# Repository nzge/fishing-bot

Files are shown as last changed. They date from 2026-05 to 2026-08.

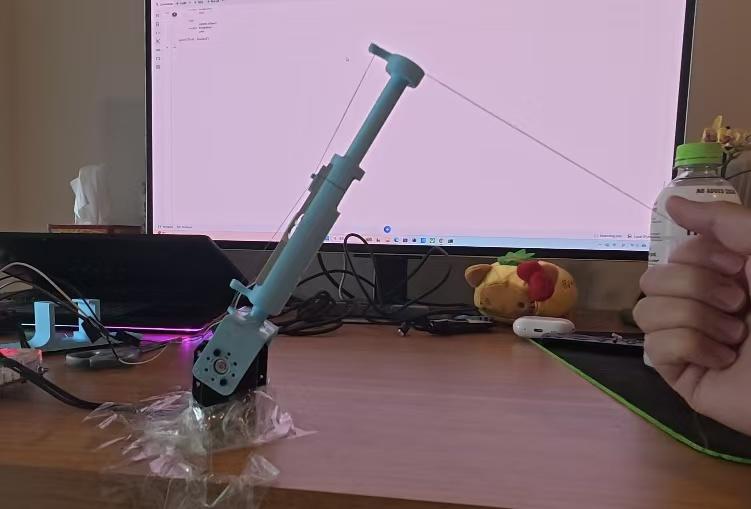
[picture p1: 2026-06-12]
docs/presentation/final presentation/ppt/media/image6.jpg

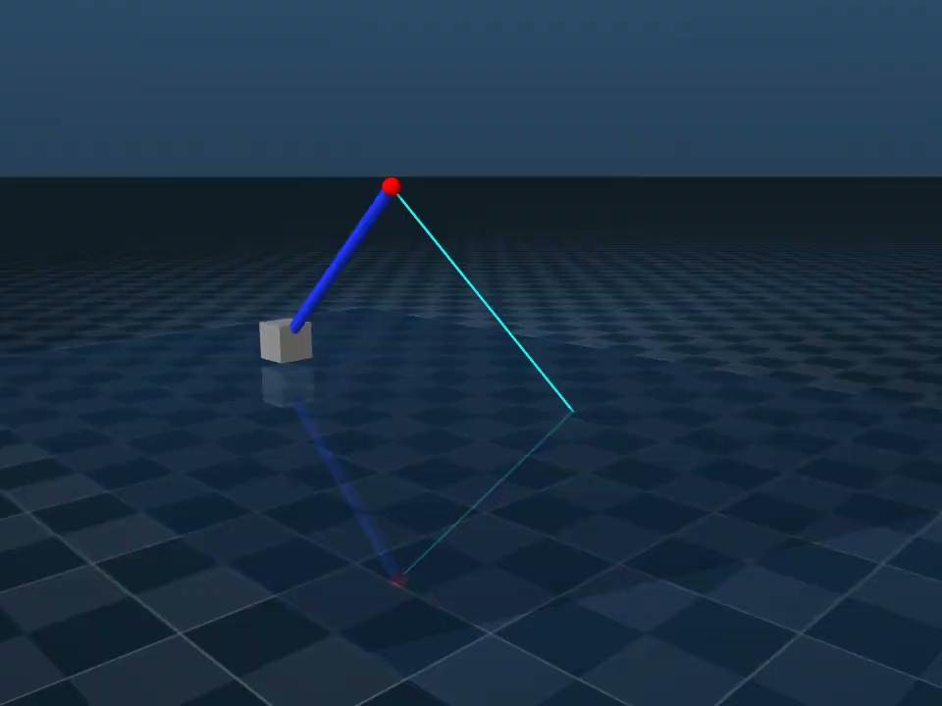
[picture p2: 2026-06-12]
docs/presentation/final presentation/ppt/media/image5.jpg

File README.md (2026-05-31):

# fishing-bot (MAE 263C)
A fishing robot

Codebase documentation: https://nzge.github.io/fishing-bot/

Tweak your fishing-robot.urdf.xacro (in your text editor).
Compile the Xacro: xacro fishing-robot.urdf.xacro use_sim:=true > fishing-robot_sim.urdf
Launch the viewer: python3 -m mujoco.viewer --file fishing-robot_sim.urdf
Inspect your meshes and joints.

## Loading mujoco viewer
- Navigate to the workspace root: cd ~/fishing-bot
- Activate your virtual environment: source .venv/bin/activate
- Launch the viewer with your XML file: python3 -m mujoco.viewer --file sim/fishing_robot.xml

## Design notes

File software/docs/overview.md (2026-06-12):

# Architecture Overview

The stack is built around a **single sim-to-real switch** (`use_sim`). The same
application nodes and topic *names* run in both modes; the hardware plugin,
optional controllers, and tension data source change.

This page is the **navigation hub**. For exhaustive detail, follow the links below.

## Start here

| I want to… | Go to |
| --- | --- |
| Understand each Python package in depth | {doc}`packages/index` |
| See all ROS 2 nodes & topics (sim vs HW) | {doc}`ros2/index` |
| Download diagrams for my report | {doc}`ros2/diagram_exports` |
| Look up launch args / YAML params | {doc}`_generated/reference/index` |
| Read Python class/function docs | {doc}`_generated/reference/api` |
| Build and run the stack | {doc}`getting_started` |

## System context

```{include} _generated/ros_graph/fragments/package_architecture.md
```

## The sim-to-real switch

The `use_sim` launch argument is resolved at **xacro preprocess time**, which
swaps the `<hardware>` plugin in the URDF *before* the controller manager loads
it:

```{list-table}
:header-rows: 1
:widths: 20 40 40

* - Concern
  - `use_sim:=true` (simulation)
  - `use_sim:=false` (hardware)
* - Hardware plugin
  - `mujoco_ros2_control`
  - `dynamixel_hardware`
* - Controller host
  - MuJoCo's bundled `ros2_control_node`
  - Standalone `controller_manager`
* - Extra ros2_control
  - `fish_effort_controller`, `tension_sensor_broadcaster`
  - *(none beyond arm controllers)*
* - Tension source
  - MuJoCo line stretch model (+ FTS fallback)
  - HX711 load cell
* - Disturbance
  - `planning/fish_agent`
  - Real fish / manual load
* - Sim-only URDF
  - `fish_swim` joint, `tension_sensor` FTS
  - Omitted from HW URDF
```

Full branching logic: {doc}`packages/bringup`.

## Closed-loop control

Both modes implement the same ROS-level tension regulation loop:

```{include} _generated/ros_graph/fragments/control_loop.md
```

Controller internals (state machine, admittance vs force-feedback):
{doc}`packages/control`.

## ROS 2 graphs at a glance

### Simulation

```{include} _generated/ros_graph/fragments/simulation_ros2_graph.md
```

Detailed node/topic tables: {doc}`ros2/simulation`.

### Hardware

```{include} _generated/ros_graph/fragments/hardware_ros2_graph.md
```

Detailed node/topic tables: {doc}`ros2/hardware`.

## Packages at a glance

```{list-table}
:header-rows: 1
:widths: 18 18 64

* - Package
  - Build type
  - Role
* - {doc}`packages/bringup`
  - ament_cmake
  - Top-level launch orchestration, controller config.
* - {doc}`packages/control`
  - ament_python
  - Admittance & force-feedback tension controllers.
* - {doc}`packages/sensors`
  - ament_python
  - `FishingTension` publisher (HX711 or sim stretch model).
* - {doc}`packages/planning`
  - ament_python
  - Virtual fish disturbance (**sim only**).
* - {doc}`packages/diagnostics`
  - ament_python
  - Run recorder + hardware bring-up self-test.
* - {doc}`packages/description`
  - ament_cmake
  - URDF/xacro, MuJoCo MJCF, STL meshes.
* - {doc}`packages/interfaces`
  - ament_cmake
  - `FishingTension.msg`.
```

## Layered architecture

```{mermaid}
flowchart TB
    subgraph L0["Layer 0 — Physical"]
        SIM["MuJoCo physics + tendon"]
        HW["Dynamixel + HX711"]
    end
    subgraph L1["Layer 1 — ros2_control"]
        CM["controller_manager / mujoco_ros2_control"]
        CTRL["joint_state_broadcaster · position_trajectory_controller"]
        SIMCTRL["fish_effort · tension_sensor (sim)"]
    end
    subgraph L2["Layer 2 — Application (Python)"]
        APP["control · sensors · planning · diagnostics"]
    end
    subgraph L3["Layer 3 — Orchestration"]
        BR["bringup/robot.launch.py"]
    end
    L0 --> L1
    L1 --> L2
    L3 --> L1
    L3 --> L2
```

## Data-flow summary

| Signal | Sim origin | HW origin | Consumer(s) |
| --- | --- | --- | --- |
| Joint positions | MuJoCo → `joint_state_broadcaster` | Dynamixel encoders | `control`, `diagnostics` |
| Line tension | Stretch model / FTS → `load_cell_node` | HX711 → `load_cell_node` | `control`, `diagnostics` |
| Joint commands | `control` → `position_trajectory_controller` | same | MuJoCo / Dynamixel |
| Fish force | `fish_agent` → `fish_effort_controller` | N/A | MuJoCo only |

Auto-generated topic index: {doc}`_generated/ros_graph/topic_index`.

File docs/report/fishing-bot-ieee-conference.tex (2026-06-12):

\documentclass[conference]{IEEEtran}
\IEEEoverridecommandlockouts

\usepackage[utf8]{inputenc}
\usepackage[T1]{fontenc}
\usepackage{cite}
\usepackage{amsmath,amssymb,amsfonts}
\usepackage{algorithmic}
\usepackage{graphicx}
\usepackage{textcomp}
\usepackage{xcolor}
\usepackage{url}
\usepackage{float}

\begin{document}

\title{Autonomous Robotic Fishing Line Tension Regulation Using Admittance Control}

\author{\IEEEauthorblockN{Nathan Ge}
\IEEEauthorblockA{\textit{Dept. of MAE} \\
\textit{UCLA}\\
Los Angeles, CA, USA}
\and
\IEEEauthorblockN{Chaoyi Hu}
\IEEEauthorblockA{\textit{Dept. of MAE} \\
\textit{UCLA}\\
Los Angeles, CA, USA}
\and
\IEEEauthorblockN{Julie Nguyen}
\IEEEauthorblockA{\textit{Dept. of MAE} \\
\textit{UCLA}\\
Los Angeles, CA, USA}
\and
\IEEEauthorblockN{Xiang Zhou}
\IEEEauthorblockA{\textit{Dept. of MAE} \\
\textit{UCLA}\\
Los Angeles, CA, USA}
}

\maketitle

\begin{abstract}
This project explores the potential of autonomous robotic fishing framework. To carry the problem into an engineering lens to build a technical framework around, we centered our robot’s function on the fishing line tension aspect of the fishing pipeline which is modelled as a force control problem. Tension regulation is fundamentally characterized by the balance of overpulling which risks the line snapping and underpulling which can lose the fish. Good anglers will respond by dynamically adjusting the orientation of the rod with intuition and feel, keeping the line tension in a safe zone. The robot will perform this balancing act intelligently with sensor feedback and precise motor control.
\end{abstract}

\begin{IEEEkeywords}
tension regulation, admittance control, robotic fishing, ROS2, force control
\end{IEEEkeywords}

\section{Overview}
This project explores the potential of autonomous robotic fishing framework. To carry the problem into an engineering lens to build a technical framework around, we centered our robot’s function on the fishing line tension aspect of the fishing pipeline which is modelled as a force control problem. Tension regulation is fundamentally characterized by the balance of overpulling which risks the line snapping and underpulling which can lose the fish. Good anglers will respond by dynamically adjusting the orientation of the rod with intuition and feel, keeping the line tension in a safe zone. The robot will perform this balancing act intelligently with sensor feedback and precise motor control.

Similar robotic fishing systems have been explored in previous projects. AlYaseen et al.\ developed an autonomous fishing rod that can detect fish bites, pull the line, and stop the motor when high resistance is detected to avoid cutting the line~\cite{b1}. This is closely related to our project because both systems use the fishing-line force as an important feedback signal. Another robotic fishing pole project used an Arduino-controlled mechanical system to cast and reel automatically through smartphone or computer control~\cite{b2}. These examples show that fishing is a suitable application for automation and robotic actuation.

Fishing has also been studied as a force-feedback and haptic simulation problem. The Stanford CHARM Lab developed a haptic fishing robot/simulator to create realistic force feedback for the user~\cite{b3}. This supports the motivation of our project because the key part of the fishing experience is not only moving the rod, but also reacting to the changing resistance from the fish. Our project extends this idea by using a physical robotic rod and an admittance controller to convert measured tension into rod motion.

The resultant robot platform is a 1 DOF robotic fishing system to control line tension following the hook set fishing phase. The robot employs sensor-based feedback control to manage tension regulation and disturbance rejection. The tension in the fishing line is detected by a load sensor, and the robot controls the rod pitch angle based on the error of the detected tension. The control system logic was modeled and solidified in simulation as a tethered robot in which the fish-like load is an external disturbance via the line. The project also creates a foundation for future work on more realistic multi-DOF fishing robots or autonomous fishing mechanisms.

\section{Control Objectives}
To carry the problem into an engineering lens to build a technical framework around, fishing can be characterized by three discrete modes: fish discovery (pre hook-set), tension regulation (post hook-set), and reeling.

Fish discovery describes the phase in which the fishing line is ‘cold’ and waiting for a fish to bite. The controller looks for a disturbance signal to indicate fish interest. A jigging action that mimics live bait may be used in this phase to increase fish hooking probability. This phase also includes holes/gaps in tension sensing caused by a fish already hooked on that escapes the jurisdiction of the control domain. Algorithms/action routines may be employed to restore control over the fish.

Looking past fish discovery is the tension regulation stage, the project’s primary control objective, which centers on maintaining tension through the fishing line. The general control structure involves a physical load sensor that approximates the force through the line, and control algorithms that take this information to modulate the tension estimation data. Tension accommodation lends itself naturally to admittance control or some sort of force regulation control methodology, both of which became primary control methods of exploration for this project.
\begin{itemize}
\item Tension regulation
\item Virtual mass-spring-damper (MSD) admittance loops
\item Highly stochastic loads handling
\end{itemize}

An additional reeling component may be added to successfully bring the fish to the desired endpoint. Reeling will also require additional hardware to pull the string inward. This would complicate the load sensing packaging and add mechanical complexity that comes with a reeling system. This particular system was not heavily pursued in our research, leaving it an avenue of future development.

\section{Methods}

\subsection{Hardware}
Image of physical robot:

\begin{figure}[H]
\centerline{}
\caption{Physical robot.}
\label{fig:physical_robot}
\end{figure}

Wiring diagram:

\begin{figure}[H]
\centerline{}
\caption{Wiring diagram.}
\label{fig:wiring_diagram}
\end{figure}

\subsection{Codebase and Simulation}
Additional details can be found in https://nzge.github.io/fishing-bot/

Building out the ROS2 codebase such that the control logic interacts seamlessly with Mujoco simulation and hardware control

\begin{table}[H]
\caption{Table: Package Descriptions}
\begin{center}
\begin{tabular}{|l|p{5.5cm}|}
\hline
\textbf{Package} & \textbf{Description} \\
\hline
Bringup & Launch configuration. Can launch simulation or hardware control based on preference. \\
\hline
Description & Mesh and model descriptors. \\
\hline
Control & Tension control package. \\
\hline
Planning & Used to control randomness of 'fish' behavior. Can be thought of as a fish agent (our disturbance). \\
\hline
Sensors & Sensor readings and publishing. \\
\hline
Interfaces & Develop protocol for inter-node communication. \\
\hline
\end{tabular}
\label{tab:packages}
\end{center}
\end{table}

\subsection{Node Architecture}
The behavior of the fish is simulated as repeatable disturbance for controlled testing.

The controller was tested in a repeatable way with a ROS2 control structure and MuJoCo simulation.

\begin{figure}[H]
\centerline{}
\caption{Node architecture.}
\label{fig:node_architecture}
\end{figure}

\subsection{Mathematical Formulation}
Control Diagram

\begin{figure}[H]
\centerline{}
\caption{Control diagram.}
\label{fig:control_diagram}
\end{figure}

High level Admittance control

The system utilizes a virtual mass-spring-damper system to

\begin{figure}[H]
\centerline{}
\caption{High-level admittance control.}
\label{fig:admittance_control}
\end{figure}

Low level PI control on theta position commands

\begin{figure}[H]
\centerline{}
\caption{Low-level PI control on theta position commands.}
\label{fig:pi_control}
\end{figure}

Inverse and forward Kinematics

\begin{figure}[H]
\centerline{}
\caption{Inverse and forward kinematics.}
\label{fig:kinematics}
\end{figure}

\section{Results}

\subsection{Error Assessment}

\subsubsection{1. Engagement and safety logic}
\begin{figure}[H]
\centerline{}
\caption{Figure 1.1. Engagement and recovery supervisor state during the hardware trial.}
\label{fig:engagement_supervisor}
\end{figure}

The engagement supervisor was also evaluated during the hardware trial. Before the line tension reached the bite-trigger condition, the controller remained in the IDLE state and commanded zero PWM, preventing the motor from responding to sensor noise or small disturbances. In this implementation, the controller was activated only when the measured tension exceeded 0.8 N for 0.10 s, representing the initial pulling event after a fish is hooked. During active control, a low-tension condition was detected when the measured tension stayed below 1.0 N. If this condition lasted for more than 1.8 s, the supervisor entered the RECOVERY state to avoid continuously pulling against a slack line. Once the measured tension recovered above 2.0 N, the controller returned to active control. The supervisor state plot shows this sequence, with transitions from IDLE to CONTROL, then to RECOVERY, and finally back to CONTROL after the tension recovered.

\subsubsection{2. Dynamic Controller Response}
\begin{figure}[H]
\centerline{}
\caption{Figure 2.1. Measured tension response during dynamic regulation.}
\label{fig:tension_dynamic}
\end{figure}

The dynamic controller response was evaluated using a trial with larger variations in the applied line tension. Fig. 2.1 shows the measured tension signal used as feedback by the controller. Since the line was pulled manually, the sharp peaks in the tension curve should not be interpreted as a standardized disturbance input. The tension signal also depends on factors such as pulling speed, pulling direction, line slack, and the contact condition of the load cell. Therefore, this figure is mainly used to show the feedback signal received by the controller during a more dynamic pulling condition, rather than to evaluate the tension curve alone.

\begin{figure}[H]
\centerline{}
\caption{Figure 2.2. Controller region switching during dynamic regulation.}
\label{fig:region_switching}
\end{figure}

The controller response to these tension changes is shown more clearly in Fig. 2.2. During the trial, the controller compares the measured tension with the target tension and the deadband, then selects the corresponding control region. When the tension rises above the desired range, the controller switches to the HIGH region, which corresponds to a release action to reduce excessive line tension. When the tension drops below the desired range, the controller returns to the LOW region, where the motor pulls back to recover line tension. The repeated LOW/HIGH transitions show that the controller is actively responding to the sign of the tension error rather than applying a fixed motor command.

\begin{figure}[H]
\centerline{}
\caption{Figure 2.3. PWM command and control components during dynamic regulation.}
\label{fig:pwm_command}
\end{figure}

Fig. 2.3 shows how these feedback decisions are converted into actuator commands. The blue curve is the final PWM command sent to the Dynamixel motor, while the orange and green curves show two major contributing terms: the high-tension release feedforward and the position compensation term. The zero-PWM line separates the two actuation directions. In this implementation, positive PWM commands are associated with release actions during high-tension events, while negative PWM commands are associated with pull-back corrections when the tension becomes too low.

The positive PWM pulses in Fig. 2.3 appears when the controller enters the HIGH region, showing that the controller is actively trying to release the rod and reduce excessive tension. After the tension decreases, the final PWM command becomes negative, which corresponds to the LOW-region pull-back action. The position compensation term changes more slowly because it depends mainly on the rod position rather than the instantaneous tension peak. As a result, the final PWM command is the combined output of tension-based correction and position-based compensation.

Overall, the agreement between Fig. 2.1, Fig. 2.2, and Fig. 2.3 shows the intended closed-loop behavior of the controller. Fig. 2.1 provides the measured tension feedback, Fig. 2.2 shows the corresponding HIGH/LOW region selection based on the tension error, and Fig. 2.3 shows the motor command generated from this feedback logic. Together, these results indicate that the robot actively responds to changes in line tension by switching control modes and commanding the actuator in the expected direction.

\subsubsection{3. Post-Transient Regulation Performance}
The post-transient regulation performance was evaluated using a separate hardware trial. This trial should not be interpreted as a standard step-response test, since the external line tension was generated manually rather than by a fixed and repeatable disturbance source. In this hardware setup, the measured tension depends not only on the rod angle, but also on the pulling force applied by hand, line slack, load-cell contact, and motor friction. Therefore, the response is expected to be slower and less uniform than a pure position-control response. For this reason, the later portion of the trial was used to evaluate whether the controller could maintain the line tension near the target once the large engagement and correction motions had passed.

\begin{figure}[H]
\centerline{}
\caption{Figure 3.1. Measured tension response after the initial engagement transient.}
\label{fig:tension_post_transient}
\end{figure}

Fig. 3.1 shows the measured tension response during this trial. The target tension was set to 3.5 N. During the initial engagement phase, the measured tension contains a large transient peak, which is mainly caused by the initial line engagement and manual pulling input. After this transient and the following correction motions, the controller brings the measured tension back toward the target range. In the later part of the trial, the tension remains close to the desired value, showing that the controller can maintain the line tension near the target under a relatively stable pulling condition.

\begin{figure}[H]
\centerline{}
\caption{Figure 3.2. Tension regulation error after the initial transient.}
\label{fig:tension_error}
\end{figure}

The tension regulation error is shown in Fig. 3.2. Instead of treating the full response as a standard settling-time test, the final portion of the trial was used as a post-transient evaluation window. Over this window, the measured tension had an average value of 3.52 N compared with the 3.5 N target. The mean absolute tension error was 0.025 N, and the RMSE was 0.036 N, corresponding to approximately 0.72\% and 1.03\% of the target tension, respectively. These values show that once the large transient response had passed, the controller was able to regulate the line tension with a small remaining error.

\begin{figure}[H]
\centerline{}
\caption{Figure 3.3. Rod joint angle during post-transient tension regulation.}
\label{fig:joint_angle}
\end{figure}

Fig. 3.3 shows the rod joint angle during the same trial, reported in degrees. The joint angle provides additional context for the tension regulation behavior shown in Fig. 3.1 and Fig. 3.2. During the initial engagement and correction phase, the tension error is relatively large, and the actuator changes the rod angle to establish line tension and reduce the error. As the measured tension approaches the target in the later part of the trial, the tension error becomes smaller and the rod joint angle also remains near a stable operating posture. This trend indicates that the actuator adjustment is consistent with the reduction of the tension error. However, the joint angle is not expected to match the tension error exactly, since the measured tension also depends on the manual pulling input, line slack, load-cell contact, and friction. Therefore, Fig. 3.3 is used to show the actuator motion and final rod posture, while Fig. 3.2 remains the main performance metric for tension regulation.

\section{Current Challenges}
Although the hardware test shows that the controller can regulate the line tension, the current setup still has several practical limitations. One major limitation is that the external line tension was applied by hand during the experiment rather than generated by a standardized disturbance source. This made the test closer to an actual fishing interaction, but it also means that the measured tension curve is affected by the pulling speed, pulling direction, and line slack. As a result, some sharp peaks and sudden drops in the tension signal should be interpreted as part of the manual interaction with the line, instead of being attributed to the controller alone. Therefore, the hardware results are mainly used to demonstrate the controller behavior under realistic manual interaction rather than to provide a standardized disturbance-response benchmark.

Another important limitation comes from the indirect relationship between motor motion and measured line tension. Unlike a pure position-control task, where the motor angle can be measured and controlled directly, the line tension depends on several physical factors between the actuator and the sensor. For example, line slack, fishing-line compliance, load-cell contact condition, and friction in the mechanism can all affect the measured tension even when the motor command is the same. As a result, small motor motions do not always produce an immediate or proportional change in tension.

This limitation is also related to the PWM-based actuation used in the current implementation. Since the motor is commanded through PWM rather than a precise torque or position controller, small corrective commands may need to overcome static friction, gravity, and mechanical resistance before visible rod motion occurs. This can make the actuator response less smooth during fine tension corrections. Therefore, the tension regulation result should be understood as the combined behavior of the controller, motor actuation, fishing line, and load-cell measurement, rather than as a direct one-to-one mapping between joint angle and tension.

\section{Future Work}
Upon further understanding of the problem, it became clear that this apparently simple tension management task has incredibly deep and rich control ideas embedded beneath the surface. This led to a deep dive of potential control tools that may bolster the robustness of the control system.

\subsection{Algorithms}
First let's consider extensive ideas on the algorithmic front. For one, if we consider taking the 1DOF control problem to the more realistic 2DOF planarized case, nonlinear coupling dynamics and orthogonal subspaces appear. But less obvious is added complication regarding sensing capabilities. Considering our limited 1D load sensing framework, we will require sensor fusion/interpretation techniques to ensure optimal tension estimation in the higher dimensional space (2D). In other words, instead of a direct linear force/tension estimation relation for the 1DOF case, we need to be aware of a more precise tension vector to perform control feedback on. If we use load sensor info and kinematic state via encoders we may employ kinematic variation/dithering to back out the tension vector estimation. But if we decide to use joint torques as well, a sensor fusion technique such as an extended kalman filter may be necessary. Furthermore, the concept of hybrid control may come into play to allow admittance in the tension management force adaptive axis and rigid positional control in perpendicular axes.

Another crucial facet of the control problem is state switching capability. Discrete states are naturally embedded within the fishing control problem, and makes the problem incredibly control rich. The transition from fish searching to hook set, or switching from having fish to losing tension are both examples of discrete switching behavior. The problem can be summarized as this: how do we ensure stable and robust discrete state switching capability? A robust Finite State Machine (FSM) must be prescribed. The current FSM implementation uses basic force thresholding that induces highly volatile “chatter” behavior, or rapid, unstable, and unnecessary state switching behavior. A few stability insurance techniques come to mind to augment our FSM. We can first employ common FSM techniques, two of which being hysteresis and debouncing. Hysteresis may help better characterize switching conditions by enforcing anisotropic force thresholds for entering and exiting a state. Debouncing adds time-based thresholding/conditioning to limit false/rapid triggering.

Another region of focus in the FSM is the transition points themself. We could apply smoothing filters to help initiate bumpless transfer and eliminate unwanted transient spikes in control effort. A crucial function of the controller is to also place the system under regions of controllability. In this particular problem, we want to avoid fish line snapping or losing tension control on the fishing being hooked onto the line. We can use tension break detection (rate of force change) and accompanying funnel synthesis to bound the tracking error control behavior. The idea of funnel synthesis can be applied to the immediate high error case where tension is suddenly lost. Funnel synthesis drops the robot controller into a safe, heavily damped recovery ‘funnel’ in case of line break preventing the robotic arm from violently whipping backward and breaking motors

This funnel synthesis concept can also be applied for control regain.

Additionally, the state behaviors themselves have to be tended to. If admittance control is being used we can use gain scheduling to customize dynamic behaviors specific to a state's concerns.

AI has relevance to control enhancement here as well. We can augment the control loop with an adaptive neural network feedforward term that learns the stochastic frequency of the fish's pulling behavior, effectively predicting the required q\_d before the tension error grows too large. Our preexisting sim-real frameworks can also be set up to build a Sim-to-real training pipeline. We use our simulation framework as an AI training tool to optimize fish tensioning behavior in the real robot. This can be primarily achieved in two ways: either we use direct RL methods to build a neural-based controller, or employ layered RL to tune controller parameters of a pre-designed control framework. Our simulation pipeline can also simply be used for adaptive control tuning without AI.

\subsection{Noise reduction and filtering techniques}
To properly target fishes for catching in an unpredictable open ocean scenario, we may require probabilistic state estimation (HMM, Bayesian filtering). This concept is often important in partial observability/limited info scenarios such as real world RL training cases. Frequency and derivative of the force may be used to distinguish between fake disturbances (boat rocking, snag on seaweed) or an actual fish. However, in the case the environment we are operating in (in our scenario it would be the ocean or a body of water) has no partial observability or obstruction concerns, we may simply bypass the problem state estimation seeks to solve by using computer vision to distinguish between a fish and ignorable entities.

\subsection{Hardware}
A few hardware-specific augmentations could be worth studying in the future, to observe their impact on tension management characteristics (transient behaviors, error attenuation, control effort).

The introduction of a redundantly actuated serial joint is one such augmentation with significant control implications. The idea was initially inspired by a desire to emulate rod compliance with active control capability. Then, the larger control picture became clear. The most practical use of the redundant serial joint is the implementation of a macro-micro manipulator structure. The lower heavy base joint handles low-frequency, high-amplitude positioning (like tracking boat's movement). A smaller, redundantly actuated serial joint near the tip can be tuned with a much higher control loop frequency to handle high-frequency stochastic disturbances. As a result, we receive the benefit of inertial decoupling: we get improved torque efficiency as jerky movements are handled by the actuator near the tip and doesn’t cause the heavy base motor downstream to respond unnecessarily and move high inertial loads.

The added joint also opens the possibility of null space optimization with the introduction of infinite joint configurations. This allows us to initiate secondary optimization objectives besides tension management such as torque minimization.

The secondary joint can also be treated as a dynamic impedance shaping element, with the redundant motor acting as a dynamically tunable physical stiffness unit that adheres to control needs.

Passive structures are another potential angle for improving dynamic performance. A compliant segment added to the end of the rod can mechanical LPF, dealing with incredibly jerky fish motion in true fishing scenarios as well as improve bumpless transfer stabilization during state transitions to reduce risky torque spikes.

The last hardware-based project enhancement has less to do with the robotic arm itself, but more so about creating an improved real-world testing rig. The idea is to create an actuatable object to mimic a fish that has planarized movement capabilities to perform varied experiments on our hardware system and its accompanying controller design

\subsection{Practical additions}
Other considerations that would bring the automated fishing system closer to a ‘market-available’ product include an actuated hooking system and a tensioning reel mechanism. This would come with its own host of hardware implementation and control framework problems.

\section*{References}

\begin{thebibliography}{00}
\bibitem{b1} M. AlYaseen, O. Alajmi, N. Al-Attal, and A. Al-Saleh, “Autonomous Fishing Rod,” College of Engineering and Applied Sciences, American University of Kuwait, Kuwait, 2019.
\bibitem{b2} J. Cook, “Robotic Fishing Pole Casts and Reels Automatically,” Hackster.io, 2019. [Online]. Available: Hackster.io.
\bibitem{b3} Stanford CHARM Lab, “Haptic Fishing Robot,” Stanford University, 2024. [Online]. Available: Stanford CHARM Lab.
\bibitem{b4} Lai, G., Zhou, S., Yang, W., Wang, X., \& Wang, F. (2023). Prescribed fixed-time adaptive neural control for manipulators with uncertain dynamics and actuator failures. Mathematics, 11(13), 2925. https://doi.org/10.3390/math11132925 Cited by: 4
\end{thebibliography}

\end{document}

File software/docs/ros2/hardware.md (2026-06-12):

# Hardware ROS 2 Graph

Launch command:

```bash
ros2 launch bringup robot.launch.py use_sim:=false
# optional: controller_type:=force_feedback hardware_check:=true
```

## Complete ROS 2 graph

```{include} ../_generated/ros_graph/fragments/hardware_ros2_graph.md
```

**Standalone source:** [`diagrams/hardware_ros2_graph.mmd`](../_static/diagrams/hardware_ros2_graph.mmd)

## What is absent on hardware

These sim-only components are **not spawned** and have **no URDF entries**
when `use_sim:=false`:

| Component | Why absent |
| --- | --- |
| `mujoco_ros2_control` node | Replaced by `controller_manager` |
| `fish_swim` joint | No virtual fish in URDF |
| `fish_effort_controller` | No fish joint to command |
| `tension_sensor_broadcaster` | No MuJoCo FTS sensor |
| `fish_agent` | Launch gated on `use_sim` |
| `/tension_sensor_broadcaster/wrench` | Topic never created |
| `/fish_effort_controller/commands` | Topic never created |
| `fish_link` TF frame | Not in HW URDF |

The dashed **"NOT present"** region in the diagram above summarises this.

## Node reference

### Infrastructure

| Node | Package | Role |
| --- | --- | --- |
| `robot_state_publisher` | `robot_state_publisher` | TF + robot description |
| `controller_manager` (`ros2_control_node`) | `controller_manager` | Realtime loop + `dynamixel_hardware` plugin |

### ros2_control controllers

| Controller | Joints | Notes |
| --- | --- | --- |
| `joint_state_broadcaster` | `Joint_1`, `Joint_2` | Publishes `/joint_states` |
| `position_trajectory_controller` | `Joint_1`, `Joint_2` | Position commands only |

No effort controllers, no sensor broadcasters.

### Application nodes

| Node | Package | Notes |
| --- | --- | --- |
| `admittance_controller` or `force_feedback_controller` | `control` | Same as sim |
| `load_cell_node` | `sensors` | `source:=hardware` — HX711 path |
| `hardware_check` | `diagnostics` | Only when `hardware_check:=true` |

## Topic catalog (hardware)

```{list-table}
:header-rows: 1
:widths: 28 22 18 32

* - Topic
  - Message
  - Publisher → Subscriber
  - Notes
* - `/joint_states`
  - `sensor_msgs/JointState`
  - `joint_state_broadcaster` → `control`, `hardware_check`
  - Dynamixel feedback
* - `/position_trajectory_controller/joint_trajectory`
  - `trajectory_msgs/JointTrajectory`
  - `control` → `position_trajectory_controller`
  - Same interface as sim
* - `/fishing_arm/tension`
  - `interfaces/FishingTension`
  - `load_cell_node` → `control`, `hardware_check`
  - From HX711 (not FTS)
* - `/tf`, `/tf_static`
  - `tf2_msgs/TFMessage`
  - `robot_state_publisher`
  - No `fish_link`
* - `/robot_description`
  - `std_msgs/String`
  - `robot_state_publisher`
  - HW URDF (no fish)
```

### Topics that exist in sim but NOT on hardware

| Topic | Sim publisher |
| --- | --- |
| `/fish_effort_controller/commands` | `fish_agent` |
| `/tension_sensor_broadcaster/wrench` | `tension_sensor_broadcaster` |
| `/clock` (sim time) | MuJoCo sim |

## Physical layer (below ROS)

```{include} ../_generated/ros_graph/fragments/hardware_data_flow.md
```

### Dynamixel path

```
JointTrajectory → position_trajectory_controller → ros2_control → DynamixelHardware
  → USB /dev/ttyUSB0 → XL430 servos (ID 1, 2) → joint encoders → /joint_states
```

### Load cell path

```
Line tension → HX711 ADC → load_cell_node.read_raw_adc()
  → calibration → moving average → /fishing_arm/tension
```

```{warning}
Implement real HX711 I/O in `read_raw_adc()` before deployment. The current
stub generates a synthetic sine wave for development.
```

## Controller differences on hardware

| Concern | Simulation | Hardware |
| --- | --- | --- |
| Jacobian for admittance | Can use TF tip/fish geometry | Falls back to `rod_length * |cos θ|` |
| Disturbance | Deterministic sine from `fish_agent` | Unpredictable real load |
| Latency | Sim-step bound | USB serial + servo response |
| Safety | Physics clamp in MJCF | `safety_tension_limit` E-stop in controller |

## Pre-flight checklist

```bash
# 1. Validate pipeline in sim first
ros2 launch bringup robot.launch.py hardware_check:=true

# 2. Run same check on hardware (controller disabled)
ros2 launch bringup robot.launch.py use_sim:=false hardware_check:=true

# 3. Closed-loop on hardware
ros2 launch bringup robot.launch.py use_sim:=false
```

## Related

- Simulation counterpart: {doc}`simulation`
- Sensor calibration: {doc}`../packages/sensors`
- Export diagram: {doc}`diagram_exports`

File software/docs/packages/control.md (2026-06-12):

# `control` — Tension Controllers

The `control` package implements **closed-loop line-tension regulation** for the
2-DOF fishing arm. It maps measured tension (from {doc}`sensors`) to joint
trajectory commands consumed by `position_trajectory_controller`.

**Source:** `software/src/control/control/`  
**Python API:** {doc}`../_generated/autoapi/control/index`  
**Parameters:** `bringup/config/params.yaml` (keyed by node name)

## Architecture

The package separates **pure control math** from **ROS 2 I/O**:

```{mermaid}
flowchart LR
    subgraph core["fishing_control_core.py (pure Python)"]
        ADM["AdmittanceControllerCore"]
        FFB["ForceFeedbackControllerCore"]
        SM["get_fishing_state()"]
    end
    subgraph ros["fishing_controller_node.py"]
        BASE["FishingControllerBase"]
        ADN["AdmittanceControllerNode"]
        FFN["ForceFeedbackControllerNode"]
    end
    subgraph entry["entry points"]
        E1["admittance_controller.py"]
        E2["force_feedback_controller.py"]
    end
    E1 --> ADN
    E2 --> FFN
    ADN --> BASE
    FFN --> BASE
    ADN --> ADM
    FFN --> FFB
    ADM --> SM
    FFB --> SM
```

| Module | Responsibility |
| --- | --- |
| `fishing_control_core.py` | State machine, tension filtering, admittance & force-feedback algorithms (notebook ports) |
| `fishing_controller_node.py` | ROS subscriptions, safety checks, trajectory publishing, config loading |
| `admittance_controller.py` | Thin `main()` → `AdmittanceControllerNode` |
| `force_feedback_controller.py` | Thin `main()` → `ForceFeedbackControllerNode` |
| `position_test_publisher.py` | Standalone open-loop sinusoid for motor validation (not launched by bringup) |

## Executables

| Command | Node name | Description |
| --- | --- | --- |
| `ros2 run control admittance_node` | `admittance_controller` | Julie's virtual admittance controller |
| `ros2 run control force_feedback_node` | `force_feedback_controller` | Chaoyi's asymmetric P controller |
| `ros2 run control position_test_publisher` | `position_test_publisher` | Manual motor sweep test |

Select at launch: `controller_type:=admittance|force_feedback|none`.

## ROS 2 interfaces

### Subscriptions

| Topic | Type | Callback | Purpose |
| --- | --- | --- | --- |
| `/fishing_arm/tension` | `interfaces/FishingTension` | `_tension_cb` | Measured line tension (N) |
| `/joint_states` | `sensor_msgs/JointState` | `_joint_state_cb` | Current `Joint_1`/`Joint_2` pos & vel |

### Publications

| Topic | Type | Content |
| --- | --- | --- |
| `/position_trajectory_controller/joint_trajectory` | `trajectory_msgs/JointTrajectory` | Position setpoints for active joints |

In **1-DOF mode** (`control_dof:=1`, default), each trajectory point sets
`Joint_1 = joint_1_hold` (locked base yaw) and `Joint_2 = pitch_cmd`.

## Control loop timing

`FishingControllerBase` runs a timer at `control_rate_hz` (default **50 Hz**):

1. **Safety gate** — if no tension received yet, or `|tension| > safety_tension_limit`, hold position (E-stop).
2. **State machine** — `get_fishing_state(t)` → `MONITOR`, `HOOK_SET`, or `REGULATE`.
3. **Tension filter** — exponential smoothing (`tension_filter_alpha`).
4. **Controller update** — algorithm-specific; produces pitch command.
5. **Publish** — `JointTrajectory` with 100 ms horizon.

See the state machine diagram in {doc}`index`.

## State machine

| State | Time window | Behaviour |
| --- | --- | --- |
| `MONITOR` | `t < bite_time` (2.4 s) | Hold `q_init`; admittance uses `f_desired = 0` |
| `HOOK_SET` | `bite_time ≤ t < bite_time + hook_duration` | Smoothstep from `q_init` → `q_hook` |
| `REGULATE` | thereafter | Track `target_tension` (3.5 N default) |

Parameters `bite_time`, `hook_duration`, and angle setpoints (`q_init`, `q_hook`,
`q_neutral`, `q_min`, `q_max`) are shared between both controllers.

## Admittance controller (Julie)

**Class:** `AdmittanceControllerCore` in `fishing_control_core.py`  
**Origin:** `scripts/mojocowithJulieController.ipynb`

Virtual **mass–spring–damper** outer loop with a force–Jacobian mapping:

1. Compute force error `f_desired - f_measured`.
2. Estimate scalar Jacobian `∂(line length)/∂θ` (geometry from TF when available, else `rod_length * |cos θ|` fallback for hardware).
3. Virtual dynamics: `m_v θ̈ = τ_force + τ_spring - b_v θ̇`.
4. Integrate to `theta_cmd`, clip to joint limits.
5. Inner PD loop computes diagnostic torque (not sent directly — `position_trajectory_controller` tracks position).

Key parameters: `m_v`, `b_v`, `k_v`, `k_f`, `kp_track`, `kd_track`, `rod_length`, `j_alpha`.

## Force-feedback controller (Chaoyi)

**Class:** `ForceFeedbackControllerCore`  
**Origin:** `scripts/mojocowithchaoyi'scontroller.ipynb`

Asymmetric proportional mapping from tension error to equilibrium pitch:

- **Below target** (`tension_error < 0`): raise rod with gain `raise_gain`.
- **Above target**: lower rod with gain `lower_gain`.
- Output smoothed via `qeq_alpha` with per-step limit `max_qeq_step`.

Key parameters: `tension_to_angle_gain`, `qeq_alpha`, `max_qeq_step`, `raise_gain`, `lower_gain`.

## Configuration loading

Parameters are declared in `load_admittance_config()` / `load_force_feedback_config()`
by iterating dataclass fields. The node name in launch (`admittance_controller` or
`force_feedback_controller`) must match the key in `params.yaml`:

```yaml
admittance_controller:
  ros__parameters:
    target_tension: 3.5
    ...
force_feedback_controller:
  ros__parameters:
    target_tension: 3.5
    ...
```

## Interactions

```{list-table}
:header-rows: 1
:widths: 22 78

* - Upstream
  - Provides measured tension and joint feedback
* - `sensors` / `load_cell_node`
  - Publishes `/fishing_arm/tension` (`FishingTension`)
* - `joint_state_broadcaster`
  - Publishes `/joint_states`
* - Downstream
  - Executes motion commands
* - `position_trajectory_controller`
  - Subscribes to `/position_trajectory_controller/joint_trajectory`
* - `bringup`
  - Selects which controller executable to launch; suppresses control during `hardware_check`
* - `diagnostics`
  - `recorder` logs tension and joint states; `hardware_check` uses same trajectory topic for open-loop moves
* - `interfaces`
  - Imports `FishingTension` message type
```

## Future: 2-DOF control

`control_dof:=2` is declared but **not yet implemented** — the node logs a warning
and continues in 1-DOF pitch-only mode. The trajectory publisher already has a
stub code path for 2-DOF joint lists.

## Related

- Tuning script: `scripts/tune_tension_control.py` (repo root)
- Compare algorithms: launch with `controller_type:=admittance` vs `force_feedback`
- API reference: {doc}`../_generated/autoapi/control/fishing_control_core/index`

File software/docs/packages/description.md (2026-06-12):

# `description` — Robot Model Assets

The `description` package holds all ** kinematic and simulation assets** for the
fishing arm: URDF/xacro, MuJoCo MJCF, and STL meshes.

**Source:** `software/src/description/`  
**Auto-generated tables:** {doc}`../_generated/reference/packages/description`

There is no runtime Python node — this package is consumed at launch time when
xacro generates the URDF and when MuJoCo loads the MJCF scene.

## Asset inventory

| Asset | Path | Used by |
| --- | --- | --- |
| Xacro macro | `urdf/fishing-robot.urdf.xacro` | `bringup` → `robot_state_publisher`, ros2_control |
| Sim URDF | `urdf/fishing-robot_sim.urdf` | Preprocessed reference |
| HW URDF | `urdf/fishing-robot_hw.urdf` | Preprocessed reference |
| MJCF scene | `urdf/fishing-robot_sim.xml` | `mujoco_ros2_control` plugin |
| Meshes | `meshes/*.STL` | Visual/collision geometry |

## Kinematic tree (both modes)

```{mermaid}
flowchart TB
    BL["base_link"]
    L1["Link_1"]
    L2["Link_2"]
    RT["rod_tip_link"]
    BL -->|"Joint_1 revolute (yaw)"| L1
    L1 -->|"Joint_2 revolute (pitch)"| L2
    L2 -->|"rod_tip_joint fixed"| RT
```

| Joint | Type | Axis | ros2_control interfaces |
| --- | --- | --- | --- |
| `Joint_1` | revolute | Z | position cmd; pos/vel/effort state |
| `Joint_2` | revolute | Y | position cmd; pos/vel/effort state |
| `rod_tip_joint` | fixed | — | Defines load cell frame |

Simulation adds:

| Joint | Type | Purpose |
| --- | --- | --- |
| `fish_swim` | prismatic | Virtual fish slide DOF |
| `fish_link` | — | Fish body frame |

## The `use_sim` xacro switch

`fishing-robot.urdf.xacro` accepts:

| Argument | Default | Effect |
| --- | --- | --- |
| `use_sim` | `true` | Select hardware plugin and sim-only joints/sensors |
| `headless` | `false` | MuJoCo viewer visibility (sim only) |

### Simulation block (`use_sim:=true`)

```xml
<plugin>mujoco_ros2_control/MujocoSystemInterface</plugin>
<param name="mujoco_model">.../fishing-robot_sim.xml</param>
<param name="initial_keyframe">starting_pose</param>
<param name="headless">...</param>
```

Additional ros2_control entries:

- **`fish_swim`** joint with effort command interface
- **`tension_sensor`** FTS sensor mapped from MJCF `tension_sensor` sensor

### Hardware block (`use_sim:=false`)

```xml
<plugin>dynamixel_hardware/DynamixelHardware</plugin>
<param name="usb_port">/dev/ttyUSB0</param>
<param name="baud_rate">57600</param>
```

No fish joint, no FTS sensor — only `Joint_1` and `Joint_2`.

## MJCF simulation scene

`fishing-robot_sim.xml` defines:

- Arm bodies matching URDF kinematics
- **Line tendon** between rod tip and fish (stiffness, rest length, damping —
  must match {doc}`sensors` `sim_line_*` parameters)
- **`tension_sensor`** force/torque sensor at rod tip
- **`fish_force`** motor on `fish_swim`
- **`starting_pose`** keyframe applied on boot

The MuJoCo plugin reads the MJCF path from the URDF `<param>` tag — no separate
launch argument needed.

## ros2_control joint ↔ Dynamixel mapping

| Joint | Dynamixel ID | Limits |
| --- | --- | --- |
| `Joint_1` | 1 | ±π rad |
| `Joint_2` | 2 | ±π rad |

Effort limit: 2.5 N·m; velocity limit: 5.76 rad/s (from URDF).

## Interactions

| Package | How it uses `description` |
| --- | --- |
| {doc}`bringup` | Processes xacro with `use_sim`, `headless`; passes URDF to all nodes |
| `mujoco_ros2_control` | Loads MJCF, steps physics, exposes sim joints/sensors |
| `dynamixel_hardware` | Maps URDF joints to USB servos |
| {doc}`sensors` | TF frame names; tendon parameter consistency |
| {doc}`planning` | Fish joint exists in sim URDF/MJCF |
| {doc}`diagnostics` | MJCF path for animation renderer |

## Related

- Full URDF source: [`fishing-robot.urdf.xacro`](https://github.com/nzge/fishing-bot/blob/main/software/src/description/urdf/fishing-robot.urdf.xacro)
- Sim vs HW ROS graphs: {doc}`../ros2/simulation`, {doc}`../ros2/hardware`

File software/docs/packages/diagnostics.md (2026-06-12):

# `diagnostics` — Recording & Bring-Up Tests

The `diagnostics` package provides **observability** (run recording, plots,
animation) and **validation** (open-loop hardware check) for the fishing stack.

**Source:** `software/src/diagnostics/diagnostics/`  
**Python API:** {doc}`../_generated/autoapi/diagnostics/index`  
**Config:** `config/diagnostics_params.yaml`

## Components overview

```{mermaid}
flowchart LR
    subgraph diag["diagnostics package"]
        REC["recorder"]
        HWC["hardware_check"]
        REN["render_animation.py<br/>(subprocess, not a node)"]
    end
    REC -->|"on shutdown"| REN
    BR["bringup"] -->|"record:=true"| REC
    BR -->|"hardware_check:=true"| HWC
```

| Executable | Node name | Launched when | Mode |
| --- | --- | --- | --- |
| `recorder` | `recorder` | `record:=true` | Typically sim |
| `hardware_check` | `hardware_check` | `hardware_check:=true` | Sim or HW |
| `render_animation.py` | — | Spawned by recorder | Sim artifacts |

Utility scripts in `scripts/` (`motor_test.py`, `sensor_test.py`) are manual
dev tools, not part of the default launch graph.

## `recorder` — Run capture & visualization

### Purpose

When `record:=true`, the recorder subscribes to joint states and tension,
buffers time series, and on shutdown:

1. Saves **`recording.npz`** (raw arrays + MJCF path).
2. Renders **`diagnostics.png`** (3-panel plot: positions, efforts, tension).
3. Spawns **`render_animation.py`** in a detached subprocess → **`animation.mp4`**.

### Subscriptions

| Topic | Type | Buffer |
| --- | --- | --- |
| `/joint_states` | `sensor_msgs/JointState` | `qpos` for `Joint_1`, `Joint_2`, `fish_swim` |
| `/fishing_arm/tension` | `interfaces/FishingTension` | measured + target tension |

### Parameters

| Parameter | Purpose |
| --- | --- |
| `output_dir` | Base directory; each run creates a timestamped subfolder |
| `mjcf_path` | Scene for offscreen render (default: `description/.../fishing-robot_sim.xml`) |
| `render_script` | Path to `render_animation.py` |
| `venv_python` | Python with MuJoCo installed (project `.venv`) |
| `auto_render` | Spawn renderer on shutdown |
| `video_format` | `mp4` or `gif` |
| `video_fps` | Animation frame rate |
| `qpos_joints` | Joint order for trajectory reconstruction |
| `arm_joints` | Joints whose effort is plotted |

Default output: `software/recordings/<timestamp>/`.

### Why a subprocess for rendering?

MuJoCo is installed in the project virtualenv, not the ROS Python environment.
The recorder uses `subprocess.Popen(..., start_new_session=True)` so launch
teardown does not kill the renderer mid-export.

### Interactions

- Reads data published by {doc}`control`, {doc}`sensors`, and `joint_state_broadcaster`.
- Uses MJCF from {doc}`description`.
- Launched by {doc}`bringup` when `record:=true`.

## `hardware_check` — Open-loop self-test

### Purpose

Verifies the ROS pipeline reaches the physical layer **without closed-loop control**:

1. **Motor test** — command each joint a small slow move via trajectory controller;
   confirm `/joint_states` reaches target within tolerance.
2. **Sensor test** — sample `/fishing_arm/tension` for N seconds; confirm finite,
   in-range values.

When `hardware_check:=true`, {doc}`bringup` **does not launch** the tension
controller, so nothing competes with test commands.

### ROS 2 interfaces

| Direction | Topic | Type |
| --- | --- | --- |
| Subscribe | `/joint_states` | `sensor_msgs/JointState` |
| Subscribe | `/fishing_arm/tension` | `interfaces/FishingTension` |
| Publish | `/position_trajectory_controller/joint_trajectory` | `trajectory_msgs/JointTrajectory` |

### Exit codes

- `0` — all checks passed
- `1` — one or more failures (printed summary table)

Works in **both sim and hardware** — validate in sim first:

```bash
ros2 launch bringup robot.launch.py hardware_check:=true
ros2 launch bringup robot.launch.py use_sim:=false hardware_check:=true
```

### Safety parameters

Tuned for gentle motion: `move_delta=0.2` rad, `move_time=2.0` s,
`position_tolerance=0.08` rad. Adjust in `diagnostics_params.yaml` for your rig.

## Launch

```bash
# Recording (via bringup)
ros2 launch bringup robot.launch.py record:=true run_duration:=30

# Hardware check (via bringup)
ros2 launch bringup robot.launch.py hardware_check:=true

# Standalone recorder (unusual)
ros2 launch diagnostics diagnostics.launch.py
```

## Related

- Recordings directory: `software/recordings/` (gitignored contents)
- Animation script: `diagnostics/scripts/render_animation.py`

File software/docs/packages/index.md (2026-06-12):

# Package Guide

This section is a **narrative, developer-oriented reference** for every package in
the `software/src/` colcon workspace. It explains *what each package does*, *how
its nodes and modules interact*, and *where to look in the source*.

For machine-generated launch/parameter tables (always in sync with the repo),
see {doc}`../_generated/reference/index`. For the Python API, see
{doc}`../_generated/reference/api`.

```{toctree}
:maxdepth: 2
:caption: Packages

bringup
control
sensors
planning
diagnostics
description
interfaces
```

## Package map

The workspace is organised into seven packages. Five are application or asset
packages; two (`bringup`, `interfaces`) are shared infrastructure.

```{include} ../_generated/ros_graph/fragments/package_architecture.md
```

## Quick reference

```{list-table}
:header-rows: 1
:widths: 14 12 10 64

* - Package
  - Build
  - Runs on HW?
  - Primary responsibility
* - {doc}`bringup`
  - ament_cmake
  - Yes
  - Top-level launch, `use_sim` switch, controller spawners, delegation to app packages.
* - {doc}`control`
  - ament_python
  - Yes
  - Tension-to-motion controllers (Julie admittance, Chaoyi force feedback).
* - {doc}`sensors`
  - ament_python
  - Yes
  - Publishes `FishingTension` from HX711 (HW) or MuJoCo line model (sim).
* - {doc}`planning`
  - ament_python
  - **Sim only**
  - Virtual fish disturbance via `fish_agent`.
* - {doc}`diagnostics`
  - ament_python
  - Yes†
  - Run recorder (sim) and hardware bring-up self-test (both modes).
* - {doc}`description`
  - ament_cmake
  - Yes
  - URDF/xacro, MJCF, STL meshes; defines ros2_control hardware plugin.
* - {doc}`interfaces`
  - ament_cmake
  - Yes
  - Custom `FishingTension.msg` shared across control, sensors, diagnostics.
```

† `recorder` is launched only when `record:=true` (typically sim). `hardware_check`
runs in both modes when `hardware_check:=true`.

## Cross-package data flow

Every tension-control run follows the same closed loop regardless of mode:

```{include} ../_generated/ros_graph/fragments/control_loop.md
```

The controller state machine is identical in both controller implementations:

```{include} ../_generated/ros_graph/fragments/fishing_state_machine.md
```

See {doc}`../ros2/index` for mode-specific ROS 2 graphs and topic tables.

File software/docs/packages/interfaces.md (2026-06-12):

# `interfaces` — Custom Messages

The `interfaces` package defines **shared ROS 2 message types** used across
multiple application packages. It is an `ament_cmake` interface package — no
runtime nodes.

**Source:** `software/src/interfaces/msg/`  
**Auto-generated tables:** {doc}`../_generated/reference/packages/interfaces`

## Messages

### `FishingTension.msg`

```
std_msgs/Header header
float32 tension_newtons
float32 target_tension_newtons
```

| Field | Type | Semantics |
| --- | --- | --- |
| `header.stamp` | `builtin_interfaces/Time` | Sample time |
| `header.frame_id` | `string` | Typically `rod_tip_link` |
| `tension_newtons` | `float32` | Measured line tension (N) — **primary control input** |
| `target_tension_newtons` | `float32` | Reserved for future feedforward/display; currently `0.0` from sensor node |

Built as `interfaces/msg/FishingTension` → included in Python as:

```python
from interfaces.msg import FishingTension
```

## Topic usage

| Topic | Publisher | Subscribers |
| --- | --- | --- |
| `/fishing_arm/tension` | {doc}`sensors` / `load_cell_node` | {doc}`control` (admittance or force_feedback), {doc}`diagnostics` (recorder, hardware_check) |

```{mermaid}
flowchart LR
    S["sensors<br/>load_cell_node"] -->|"/fishing_arm/tension<br/>FishingTension"| C["control<br/>tension controller"]
    S --> D1["diagnostics<br/>recorder"]
    S --> D2["diagnostics<br/>hardware_check"]
```

## Design rationale

A custom message (rather than reusing `geometry_msgs/WrenchStamped` or
`std_msgs/Float64`) provides:

1. **Semantic clarity** — tension in Newtons along the line, not a generic wrench.
2. **Stable API** — controllers depend on one field (`tension_newtons`).
3. **Room for extension** — `target_tension_newtons` for future overlay/debug.

The sim path internally uses `WrenchStamped` from `tension_sensor_broadcaster`
but converts to `FishingTension` before the control layer.

## Build dependency graph

Any package that imports `FishingTension` must declare:

```xml
<depend>interfaces</depend>
```

Current dependents: `control`, `sensors`, `diagnostics`.

## Related standard messages

The stack also uses these **non-custom** types (not in `interfaces`):

| Message | Topic(s) | Package |
| --- | --- | --- |
| `trajectory_msgs/JointTrajectory` | `/position_trajectory_controller/joint_trajectory` | `control`, `diagnostics` |
| `sensor_msgs/JointState` | `/joint_states` | all controllers, diagnostics |
| `geometry_msgs/WrenchStamped` | `/tension_sensor_broadcaster/wrench` | `sensors` (sim fallback) |
| `std_msgs/Float64MultiArray` | `/fish_effort_controller/commands` | `planning` |

See {doc}`../ros2/index` for the complete topic catalog.

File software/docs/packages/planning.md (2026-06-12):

# `planning` — Virtual Fish (Simulation Only)

The `planning` package provides an **environmental disturbance source** for
MuJoCo simulation. It models a fish fighting on the line without any direct
coupling to the tension controller.

**Source:** `software/src/planning/planning/fish_agent.py`  
**Python API:** {doc}`../_generated/autoapi/planning/index`  
**Config:** `config/fish_params.yaml`

```{important}
`fish_agent` is launched **only when `use_sim:=true`**. It does not run on
real hardware — the disturbance there comes from an actual fish (or manual load).
```

## Design: indirect coupling

The fish never publishes to the controller. The causal chain is:

```{include} ../_generated/ros_graph/fragments/sim_data_flow.md
```

1. `fish_agent` publishes effort commands.
2. `fish_effort_controller` (ros2_control) forwards them to MuJoCo's `fish_force` motor.
3. MuJoCo applies force on the `fish_swim` prismatic joint.
4. The line tendon transmits force to the rod tip.
5. {doc}`sensors` measures resulting tension.
6. {doc}`control` reacts to measured tension.

This mirrors real fishing: the controller only sees the load cell, not the fish.

## Node: `fish_agent`

### Disturbance model

Sinusoidal "fight" superimposed on a steady pull:

```
force(t) = mean_force + amplitude * sin(2π * frequency * t)
```

Default profile (from `fish_params.yaml`):

| Parameter | Value | Meaning |
| --- | --- | --- |
| `mean_force` | 3.5 N | Steady pull — centred on controller `target_tension` |
| `amplitude` | 1.2 N | Fight oscillation peak |
| `frequency` | 0.5 Hz | Thrash rate |
| `publish_frequency` | 50 Hz | Command update rate |

### ROS 2 interfaces

| Direction | Topic | Type |
| --- | --- | --- |
| **Publish** | `/fish_effort_controller/commands` | `std_msgs/Float64MultiArray` |

The message `data` field contains a single element: effort in Newtons applied
along the fish slide joint axis.

### ros2_control path

Configured in `bringup/config/controllers.yaml`:

```yaml
fish_effort_controller:
  ros__parameters:
    joints: [fish_swim]
    interface_name: effort
```

The spawner runs only in sim (`robot.launch.py`, `IfCondition(use_sim)`).

## URDF / MJCF requirements

The fish exists only in simulation:

- **URDF** (`fishing-robot.urdf.xacro`): `fish_link` + `fish_swim` prismatic joint
  gated on `use_sim`.
- **MJCF** (`fishing-robot_sim.xml`): fish body, `fish_force` motor, line tendon.

See {doc}`description` for asset details.

## Interactions

| Component | Interaction |
| --- | --- |
| {doc}`bringup` | Includes `fish.launch.py` when `use_sim:=true` |
| `fish_effort_controller` | Subscribes to commands; writes effort to MuJoCo |
| {doc}`sensors` | Indirect — fish force → line tension → `/fishing_arm/tension` |
| {doc}`control` | Indirect — regulates tension caused by fish |
| {doc}`diagnostics` / `recorder` | Logs resulting joint/tension time series |

## Tuning tips

- Increase `amplitude` or `frequency` to stress-test controller stability.
- Match `mean_force` to `target_tension` in `params.yaml` for steady-state tracking tests.
- Disable fish entirely by not launching planning (would require custom launch) or
  set `mean_force:=0 amplitude:=0`.

## Launch

```bash
# Included automatically in sim bringup; standalone:
ros2 launch planning fish.launch.py
```

Only useful when `fish_effort_controller` is already active in MuJoCo.

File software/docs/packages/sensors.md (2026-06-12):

# `sensors` — Line Tension Sensing

The `sensors` package publishes **`/fishing_arm/tension`** as an
`interfaces/FishingTension` message. A single node — `load_cell_node` — serves
both hardware and simulation by switching its **`source`** parameter.

**Source:** `software/src/sensors/sensors/load_cell_publisher.py`  
**Python API:** {doc}`../_generated/autoapi/sensors/index`  
**Config:** `config/sensor_params.yaml`

## Design principle: one node, two backends

The tension controller ({doc}`control`) always subscribes to `/fishing_arm/tension`.
It never needs to know whether tension came from a physical HX711 or a MuJoCo
simulation model. `bringup` sets the backend at launch:

```python
source = 'sim_fts' if use_sim else 'hardware'
```

```{mermaid}
flowchart TB
    LC["load_cell_node"]
    LC -->|"always"| TOP["/fishing_arm/tension<br/>FishingTension"]

    subgraph hw["source:=hardware"]
        HX["HX711 ADC<br/>read_raw_adc()"]
        CAL["calibration_offset · calibration_scale"]
        HX --> CAL --> LC
    end

    subgraph sim["source:=sim_fts"]
        TF["TF: rod_tip_link → fish_link<br/>line length L"]
        STR["Hooke's law:<br/>k(L-L0) + c dL/dt"]
        WRENCH["/tension_sensor_broadcaster/wrench<br/>(fallback)"]
        TF --> STR --> LC
        WRENCH -.->|"if TF unavailable"| LC
    end
```

## Node: `load_cell_node`

### Parameters (from `sensor_params.yaml`)

| Parameter | Default | Purpose |
| --- | --- | --- |
| `calibration_offset` | `1245.0` | HX711 zero-load ADC reading |
| `calibration_scale` | `0.0023` | N per ADC bit |
| `use_moving_average` | `true` | Enable sliding-window smoothing |
| `window_size` | `10` | Moving average length |
| `publish_frequency` | `80.0` | Timer rate (Hz) |
| `tension_max_threshold` | `20.0` | Log warning above this (N) |
| `noise_floor` | `0.1` | Zero out sub-threshold readings |
| `frame_id` | `rod_tip_link` | Message header frame |
| `source` | `hardware` | `hardware` or `sim_fts` (overridden by launch) |
| `sim_line_stiffness` | `220.0` | Must match MJCF tendon stiffness |
| `sim_line_springlength` | `0.20` | Rest length L₀ (m) |
| `sim_line_damping` | `1.5` | Damping on stretch rate |
| `sim_rod_frame` | `rod_tip_link` | TF frame at rod tip |
| `sim_fish_frame` | `fish_link` | TF frame at fish |

### Hardware path (`source:=hardware`)

1. `read_raw_adc()` reads the HX711 (currently a **placeholder** with simulated
   sine disturbance for development).
2. Apply `(raw - calibration_offset) * calibration_scale` → Newtons.
3. Zero out below `noise_floor`.
4. Optional moving average over `window_size` samples.
5. Publish `FishingTension`.

```{warning}
`read_raw_adc()` is still a stub. Replace with real SPI/serial HX711 driver
before trusting hardware tension values.
```

### Simulation path (`source:=sim_fts`)

Primary method — **stretch model** matching the MJCF tendon:

1. Lookup TF transform `rod_tip_link` → `fish_link`.
2. Compute line length `L = ||translation||`.
3. Stretch `= max(L - sim_line_springlength, 0)`.
4. Tension `= k * stretch + c * dL/dt` (damping only on lengthening).
5. Fallback: if TF unavailable, subscribe to
   `/tension_sensor_broadcaster/wrench` and use force magnitude.

The stretch model is preferred because it matches the controller's physical
expectation and is independent of the FTS frame orientation.

## ROS 2 interfaces

### Publications

| Topic | Type | Rate |
| --- | --- | --- |
| `/fishing_arm/tension` | `interfaces/FishingTension` | `publish_frequency` (80 Hz) |

Message fields:

- `tension_newtons` — measured tension (primary signal for controllers)
- `target_tension_newtons` — reserved (currently always `0.0`; controllers use params instead)

### Subscriptions (sim only)

| Topic | Type | When |
| --- | --- | --- |
| `/tension_sensor_broadcaster/wrench` | `geometry_msgs/WrenchStamped` | `source==sim_fts`, TF fallback |

### TF (sim only)

Uses `tf2_ros.Buffer` + `TransformListener` to compute inter-frame distance.
Depends on `robot_state_publisher` publishing the tree that includes `fish_link`
(sim URDF only).

## Signal processing pipeline

Each timer tick (`timer_callback`):

```
raw reading → noise floor → moving average → FishingTension publish
                ↓
         threshold warning (log)
```

The moving average uses a fixed-length `collections.deque` — O(1) append and
bounded memory.

## Interactions

| Package / node | Relationship |
| --- | --- |
| {doc}`control` | Subscribes to `/fishing_arm/tension`; E-stop on missing/stale data |
| {doc}`bringup` | Sets `source` from `use_sim`; always includes `sensor.launch.py` |
| {doc}`diagnostics` | `recorder` and `hardware_check` subscribe to tension topic |
| {doc}`description` | Defines `rod_tip_link`, `fish_link` frames; MJCF tendon params |
| `tension_sensor_broadcaster` | Sim-only ros2_control broadcaster → wrench topic |
| {doc}`interfaces` | Defines `FishingTension.msg` |

## Physical layer diagrams

- Simulation chain: {doc}`../ros2/simulation` (data flow section)
- Hardware chain: {doc}`../ros2/hardware` (data flow section)

## Launch

```bash
# Normally launched by bringup; standalone:
ros2 launch sensors sensor.launch.py source:=hardware
ros2 launch sensors sensor.launch.py source:=sim_fts
```

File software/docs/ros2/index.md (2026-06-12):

# ROS 2 Communication Graph

This section documents every **node**, **topic**, and **message type** in the
fishing-arm stack, with explicit separation between **MuJoCo simulation** and
**Dynamixel hardware** modes.

## Mode selection recap

A single launch argument — **`use_sim`** — drives all structural differences.
Application nodes (`control`, `sensors`) run in both modes; only their *data
sources* and *which ros2_control controllers spawn* change.

```{list-table}
:header-rows: 1
:widths: 22 39 39

* - Concern
  - Simulation (`use_sim:=true`)
  - Hardware (`use_sim:=false`)
* - ros2_control host
  - `mujoco_ros2_control/ros2_control_node`
  - `controller_manager/ros2_control_node`
* - Hardware plugin (URDF)
  - `mujoco_ros2_control/MujocoSystemInterface`
  - `dynamixel_hardware/DynamixelHardware`
* - Extra controllers
  - `fish_effort_controller`, `tension_sensor_broadcaster`
  - *(none)*
* - Disturbance
  - `planning/fish_agent`
  - Real fish / manual load
* - Tension source param
  - `sensors`: `source:=sim_fts`
  - `sensors`: `source:=hardware`
* - Sim-only nodes
  - `fish_agent`, `recorder` (when recording)
  - —
* - Time
  - `use_sim_time:=true` on MuJoCo node
  - wall clock
```

```{toctree}
:maxdepth: 2

simulation
hardware
topic_reference
diagram_exports
```

## Shared closed-loop (both modes)

Regardless of mode, tension control follows the same ROS-level loop:

```{include} ../_generated/ros_graph/fragments/control_loop.md
```

## Side-by-side node presence

```{list-table}
:header-rows: 1
:widths: 30 15 15

* - Node / component
  - Simulation
  - Hardware
* - `robot_state_publisher`
  - ✓
  - ✓
* - `mujoco_ros2_control` / `ros2_control_node`
  - ✓
  - —
* - `controller_manager` / `ros2_control_node`
  - —
  - ✓
* - `joint_state_broadcaster`
  - ✓
  - ✓
* - `position_trajectory_controller`
  - ✓
  - ✓
* - `fish_effort_controller`
  - ✓
  - ✗
* - `tension_sensor_broadcaster`
  - ✓
  - ✗
* - `admittance_controller` / `force_feedback_controller`
  - ✓
  - ✓
* - `load_cell_node`
  - ✓
  - ✓
* - `fish_agent`
  - ✓
  - ✗
* - `recorder`
  - ✓ (if `record:=true`)
  - optional†
* - `hardware_check`
  - ✓ (if flag set)
  - ✓ (if flag set)
```

† Recorder is sim-oriented (MuJoCo animation) but will still capture plots if launched on hardware.

## Controller manager services

Both modes expose the standard ros2_control service API on `/controller_manager`:

- `~/list_controllers`
- `~/load_controller` / `~/unload_controller`
- `~/switch_controller`

Spawner nodes exit after loading; the manager and loaded controllers persist.

## TF tree

Published by `robot_state_publisher` from the processed URDF:

**Both modes:** `base_link` → `Link_1` → `Link_2` → `rod_tip_link`

**Simulation only:** `base_link` → `fish_link` (via `fish_swim` prismatic joint)

`sensors/load_cell_node` uses TF (`rod_tip_link` ↔ `fish_link`) in sim to
compute line length for the stretch tension model.

## Quick topic index

See {doc}`topic_reference` for the auto-generated full table, or the mode-specific pages:

- {doc}`simulation` — complete sim graph + physics-layer explanation
- {doc}`hardware` — HW graph + HX711/Dynamixel path
- {doc}`diagram_exports` — standalone `.mmd` files for reports

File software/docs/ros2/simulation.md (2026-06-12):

# Simulation ROS 2 Graph

Launch command:

```bash
ros2 launch bringup robot.launch.py
# optional: headless:=true record:=true run_duration:=30
```

## Complete ROS 2 graph

The diagram below is the **authoritative sim-mode communication graph**. The same
source file is available for reports at
[`diagrams/simulation_ros2_graph.mmd`](../_static/diagrams/simulation_ros2_graph.mmd)
(also copied to `_static/diagrams/` on every build).

```{include} ../_generated/ros_graph/fragments/simulation_ros2_graph.md
```

```{tip}
**Download for your report:** after building docs, open
`_build/html/_static/diagrams/simulation_ros2_graph.mmd` or use
[diagram_exports](diagram_exports.md) for SVG export instructions.
```

## Node reference

### Infrastructure

| Node | Package | Role |
| --- | --- | --- |
| `robot_state_publisher` | `robot_state_publisher` | Publishes `/tf`, `/tf_static`, `/robot_description` from URDF |
| `mujoco_ros2_control` (`ros2_control_node`) | `mujoco_ros2_control` | MuJoCo physics + hosts `/controller_manager`; loads `fishing-robot_sim.xml` |

### ros2_control controllers

| Controller | Type | Joint(s) | ROS interface |
| --- | --- | --- | --- |
| `joint_state_broadcaster` | `JointStateBroadcaster` | all | Pubs `/joint_states` |
| `position_trajectory_controller` | `JointTrajectoryController` | `Joint_1`, `Joint_2` | Subs `.../joint_trajectory` |
| `fish_effort_controller` | `ForwardCommandController` | `fish_swim` | Subs `.../commands` |
| `tension_sensor_broadcaster` | `ForceTorqueSensorBroadcaster` | FTS sensor | Pubs `.../wrench` |

Controller manager update rate: **100 Hz** (`controllers.yaml`).

### Application nodes

| Node | Package | Condition |
| --- | --- | --- |
| `admittance_controller` or `force_feedback_controller` | `control` | unless `hardware_check` |
| `load_cell_node` | `sensors` | always (`source:=sim_fts`) |
| `fish_agent` | `planning` | always in sim |
| `recorder` | `diagnostics` | `record:=true` |

## Topic catalog (simulation)

```{list-table}
:header-rows: 1
:widths: 28 22 18 32

* - Topic
  - Message
  - Publisher → Subscriber
  - Notes
* - `/joint_states`
  - `sensor_msgs/JointState`
  - `joint_state_broadcaster` → `control`, `recorder`
  - Includes `fish_swim` position
* - `/position_trajectory_controller/joint_trajectory`
  - `trajectory_msgs/JointTrajectory`
  - `control` → `position_trajectory_controller`
  - 50 Hz commands typical
* - `/fishing_arm/tension`
  - `interfaces/FishingTension`
  - `load_cell_node` → `control`, `recorder`
  - Primary feedback signal
* - `/tension_sensor_broadcaster/wrench`
  - `geometry_msgs/WrenchStamped`
  - `tension_sensor_broadcaster` → `load_cell_node`
  - Fallback if TF stretch model unavailable
* - `/fish_effort_controller/commands`
  - `std_msgs/Float64MultiArray`
  - `fish_agent` → `fish_effort_controller`
  - Single effort value (N)
* - `/tf`, `/tf_static`
  - `tf2_msgs/TFMessage`
  - `robot_state_publisher` → `load_cell_node`
  - Needed for line length
* - `/robot_description`
  - `std_msgs/String`
  - `robot_state_publisher`
  - URDF string
* - `/clock`
  - `rosgraph_msgs/Clock`
  - sim time source
  - `use_sim_time:=true`
```

## Physics layer (below ROS)

ROS messages are the boundary; inside MuJoCo the causal chain is:

```{include} ../_generated/ros_graph/fragments/sim_data_flow.md
```

### Key MJCF parameters (must stay consistent)

| Parameter | MJCF location | `sensors` param |
| --- | --- | --- |
| Line stiffness 220 N/m | tendon | `sim_line_stiffness` |
| Rest length 0.20 m | tendon | `sim_line_springlength` |
| Damping 1.5 | tendon | `sim_line_damping` |

Mismatch between MJCF and `sensor_params.yaml` will cause sim/HW tuning divergence.

## Typical message flow (one control cycle)

```{mermaid}
sequenceDiagram
    participant F as fish_agent
    participant FEC as fish_effort_controller
    participant MJ as MuJoCo
    participant TSB as tension_sensor_broadcaster
    participant LC as load_cell_node
    participant C as admittance_controller
    participant PTC as position_trajectory_controller

    F->>FEC: Float64MultiArray (effort)
    FEC->>MJ: fish_swim effort
    MJ->>MJ: tendon dynamics
    LC->>LC: TF stretch model
    TSB-->>LC: WrenchStamped (fallback)
    LC->>C: FishingTension
    C->>PTC: JointTrajectory
    PTC->>MJ: Joint_1/2 position
    MJ->>C: JointState (via /joint_states)
```

## Related

- Hardware counterpart: {doc}`hardware`
- Package details: {doc}`../packages/index`
- Export diagram: {doc}`diagram_exports`

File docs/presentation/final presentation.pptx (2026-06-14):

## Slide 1

GoFish!: A Tension Regulation Fishing Robot

TEAM 17

Nathan Ge, Chaoyi Hu, Julie Nguyen, Xiang Zhou

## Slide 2

Overview

## Project Overview & Motivation

- Project Goal
  - Develop a 1-DOF rigid robotic fishing rod
  - Simulate fish-fighting interaction under controlled testing
  - Develop a control paradigm to regulate fishing-line tension near a 3.5 N target with a ±0.1 N deadband.
- Motivation / Literature
  - Prior fishing haptic devices show that force feedback improves realism in fishing simulation.
  - Fishing-rod haptic displays have also been studied for presenting force sensation through a rod-and-line structure.
- Applications
  - Fishing training simulator
  - Entertainment / interactive game controller
  - Robotics force-feedback education
- System Concept

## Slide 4

Hardware

## Hardware Test

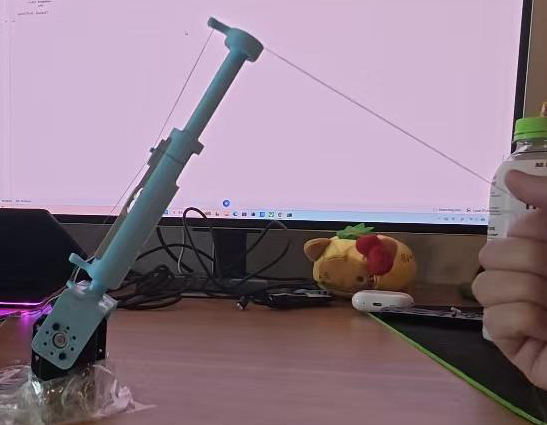
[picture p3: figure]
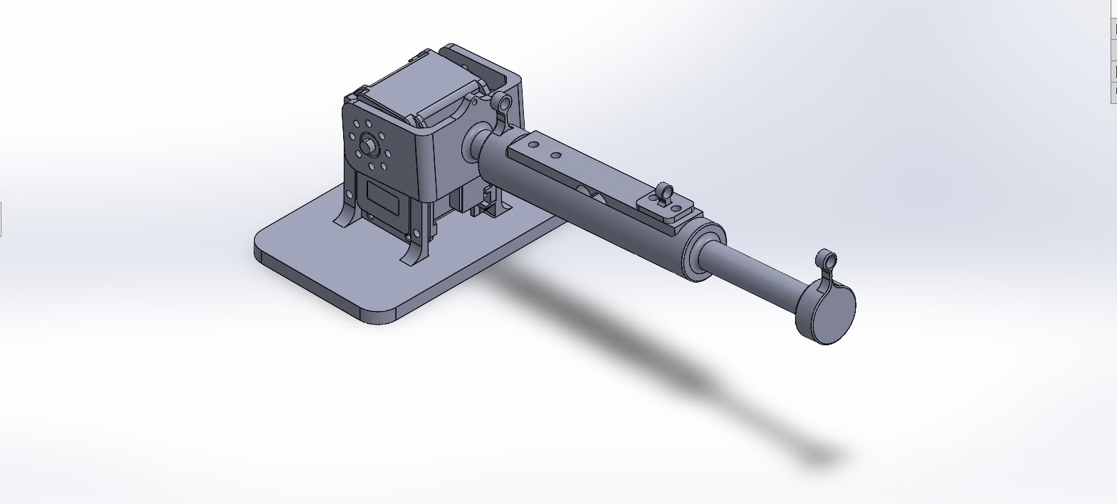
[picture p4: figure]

1DOF

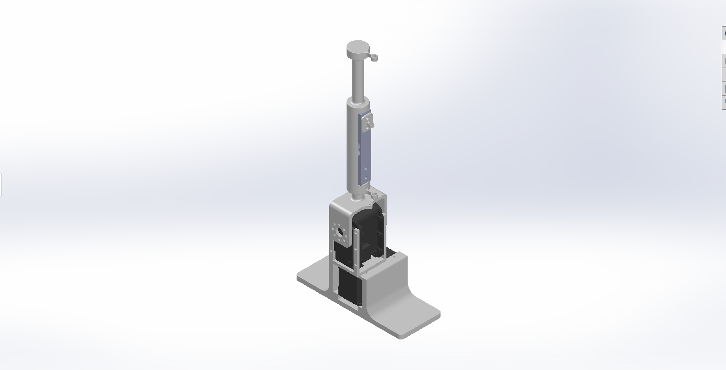
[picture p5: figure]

2DOF

## Wiring Diagram

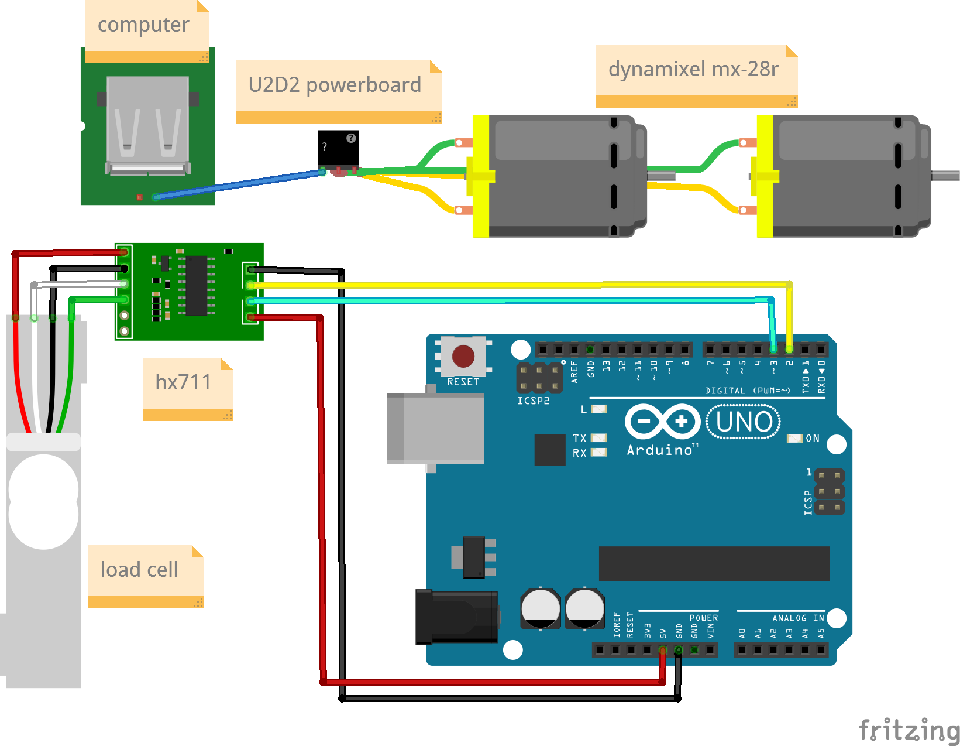
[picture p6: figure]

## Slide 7

Software

## Simulation (mujoco)

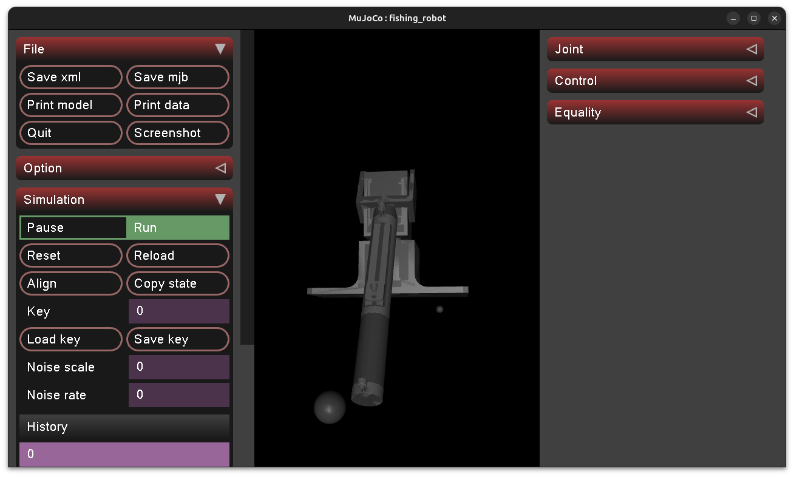
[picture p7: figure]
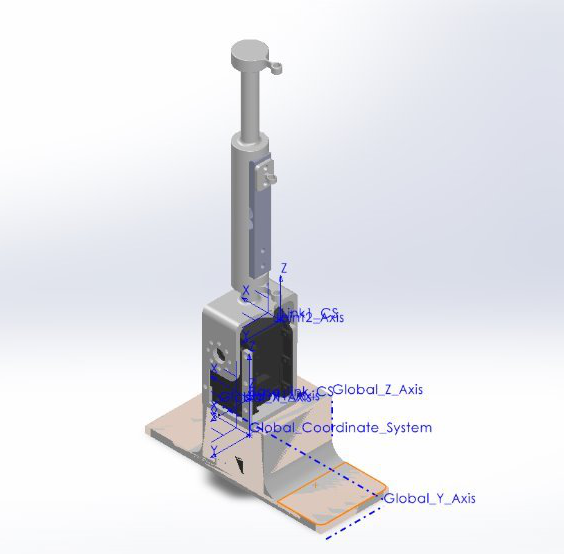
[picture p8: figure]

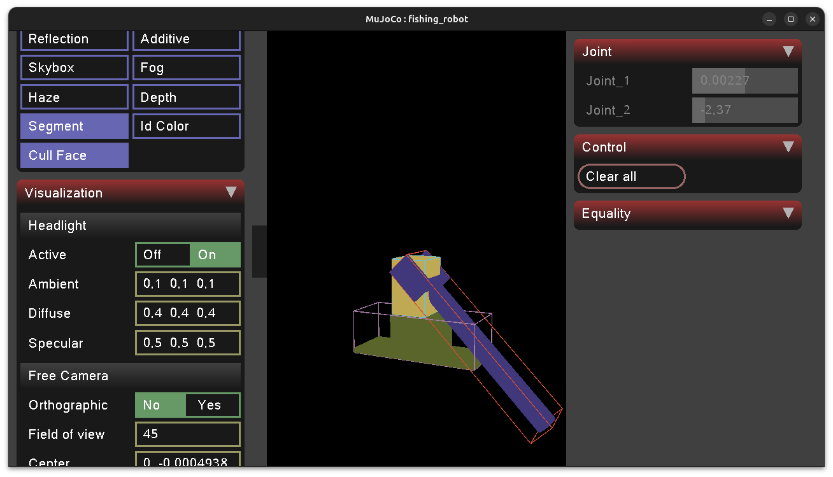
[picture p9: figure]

## Codebase (true implementation)

ROS2 - software architecture modularity

Building out the ROS2 codebase such that the control logic interacts seamlessly with Mujoco simulation and hardware control
- Bringup: launch configuration. Can launch simulation or hardware control based on preference
- Description: mesh and model descriptors
- Control: tension control package
- Planning: will likely be used to control randomness of 'fish' behavior. Can be thought of as a fish agent (our disturbance)
- Sensors: sensor readings and publishing
- Interfaces: develop protocol for inter-node communication

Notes: unfortunately we had to default back to our simpler mujoco simulation and hardware control pipeline
given software development complexities associated with ros2

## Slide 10

Controller & Simulation

## Controller Diagram (Admittance Control)

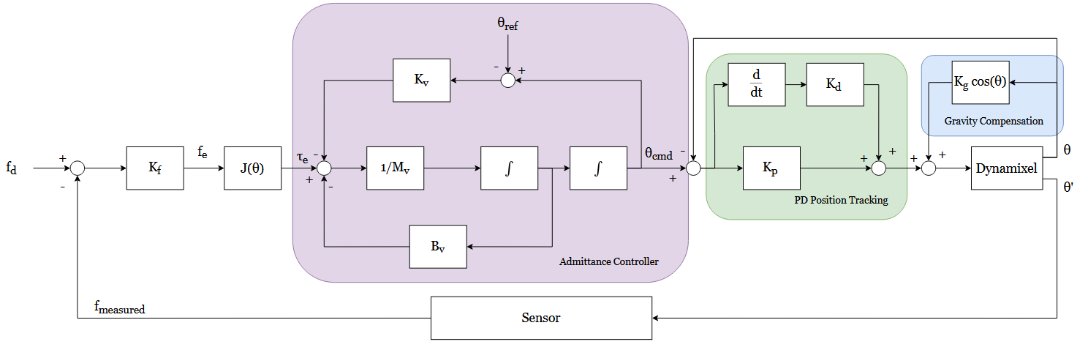
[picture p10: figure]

Mv θ¨cmd+Bv θ˙cmd+Kv(θcmd−θref) = −J(θ) Kf(fd−fmeasured)

## Admittance Controller Results

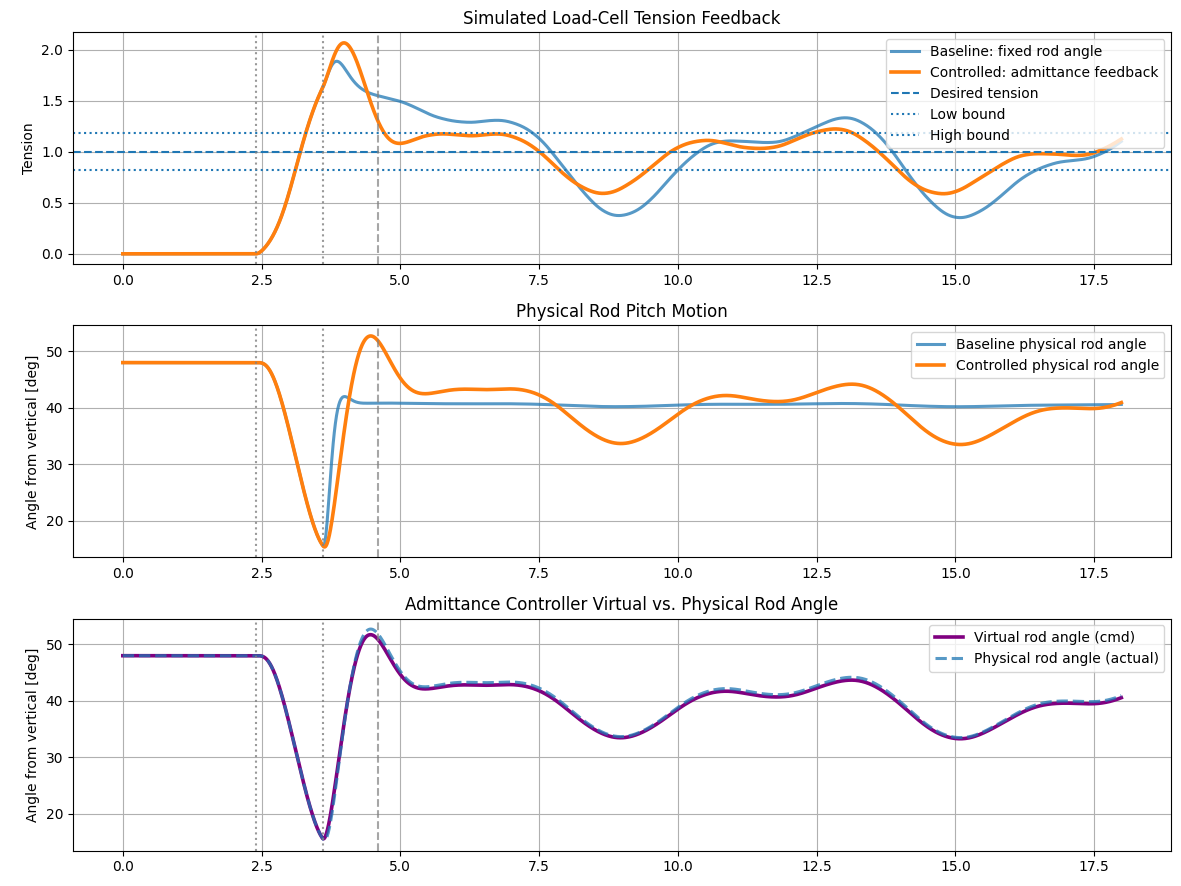
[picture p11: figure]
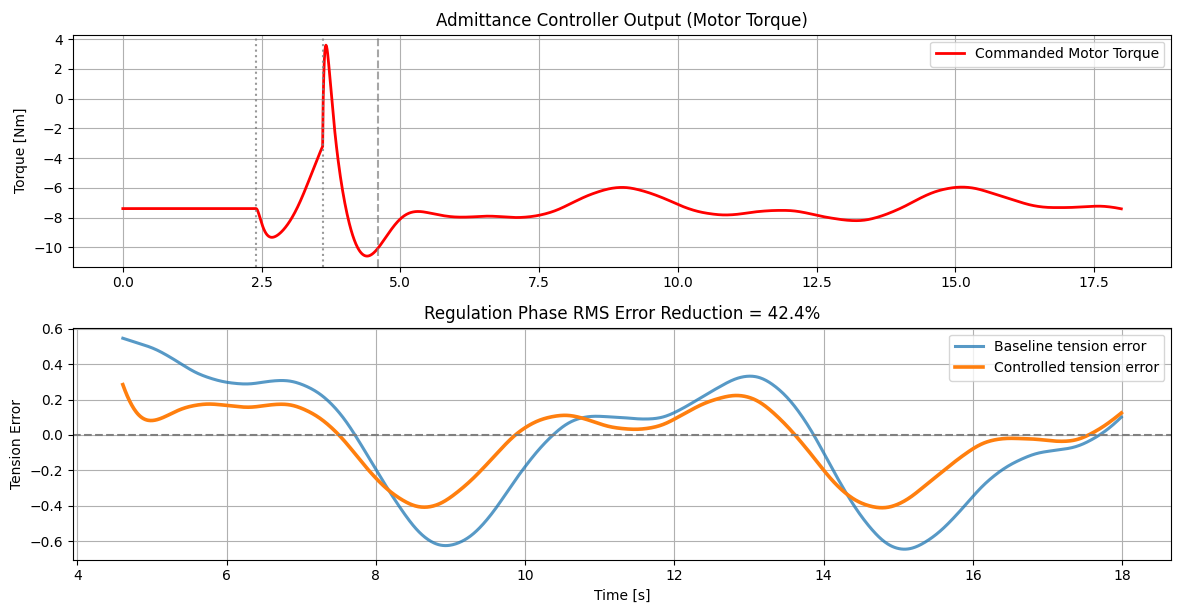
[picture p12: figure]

## Controller Diagram (Proportional Force Control)

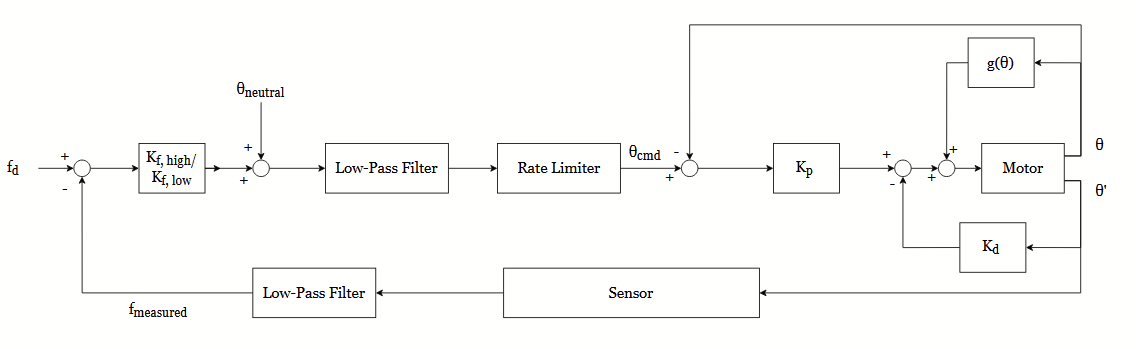
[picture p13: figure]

Kf, low/high(fd−fmeasured) + θneutral= θcmd

## Admittance Controller Force Controller

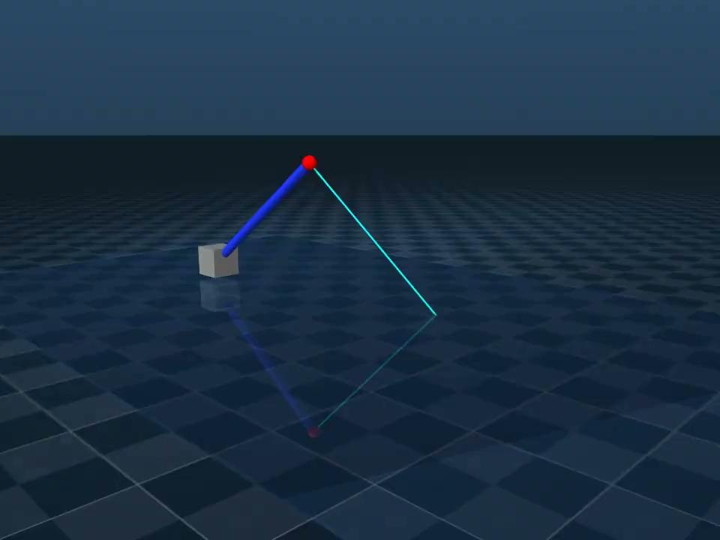
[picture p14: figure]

## Controller Comparison

Admittance Control

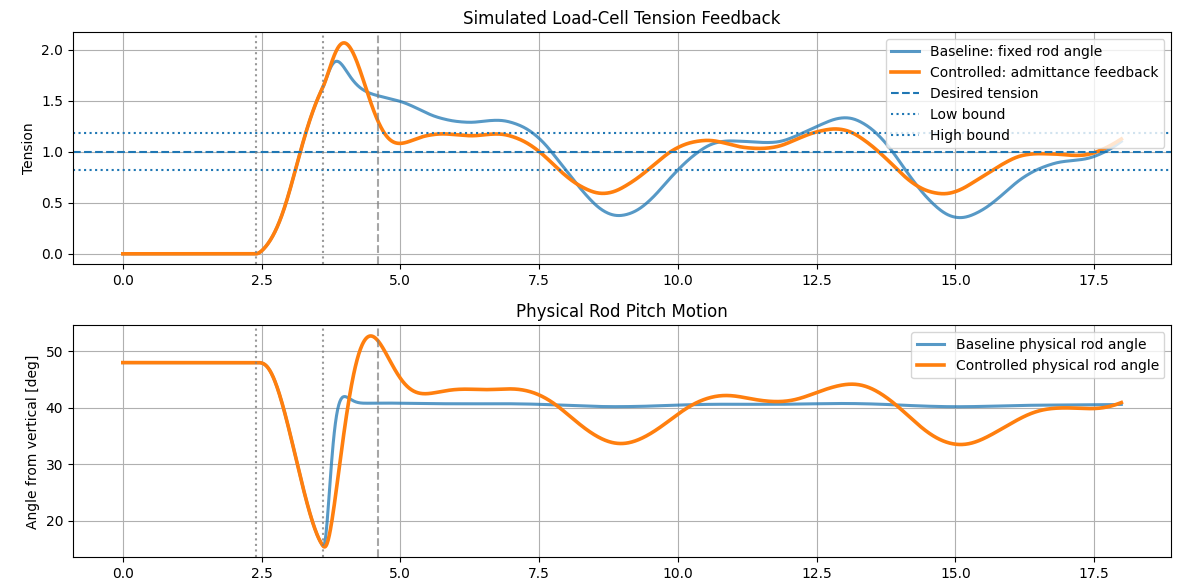
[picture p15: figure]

Proportional Force Control

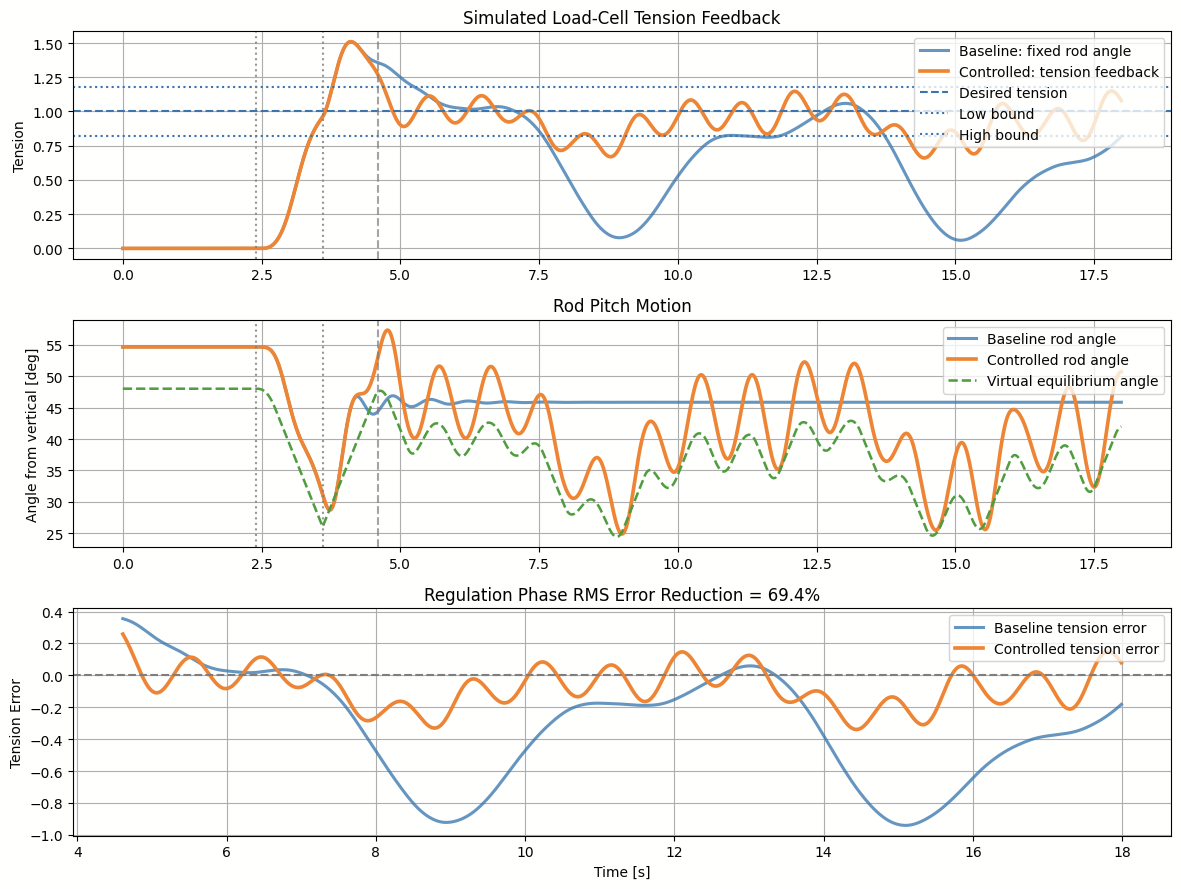
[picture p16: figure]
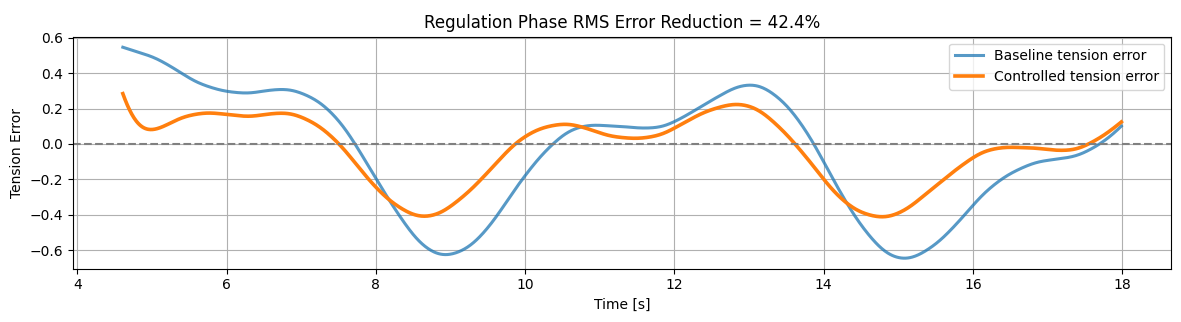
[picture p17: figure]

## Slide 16

Results

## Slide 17

Manual pulling creates line-tension changes, and the rod responds through the Dynamixel motor.

## Dynamic Controller Response

Test condition: Rapid manual pulls were applied to create sudden line-tension changes.
Key result: the controller switched between release and pull-back actions, and the PWM command changed accordingly.

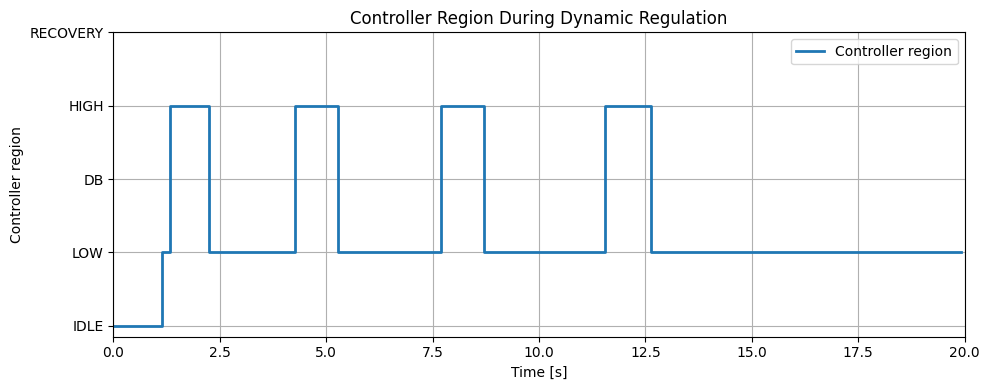
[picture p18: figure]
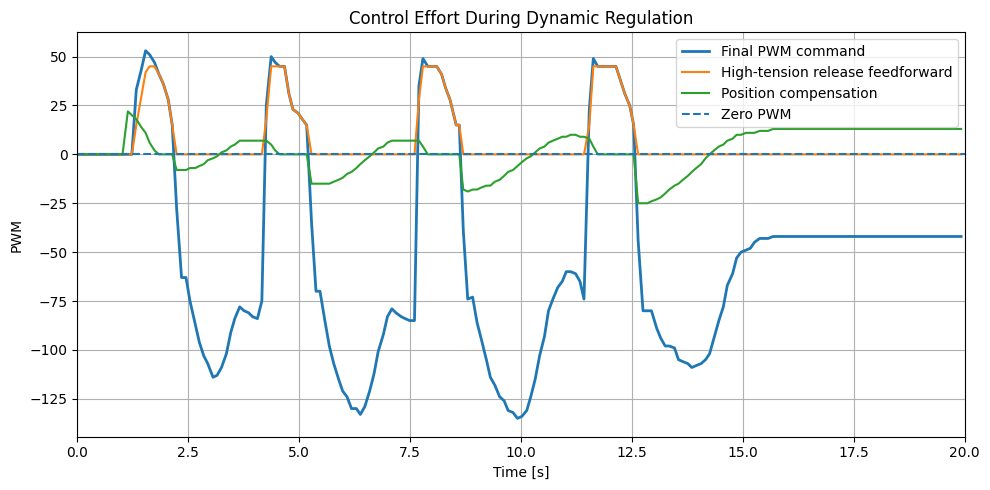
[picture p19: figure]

## Post-Transient Regulation Accuracy

Test condition:
Initial manual pull followed by steady holding to evaluate whether the controller can return the tension near the 3.5 N target.
Takeaway:
After the initial engagement and correction phase, the controller reduced the tension error and maintained the measured tension close to the target

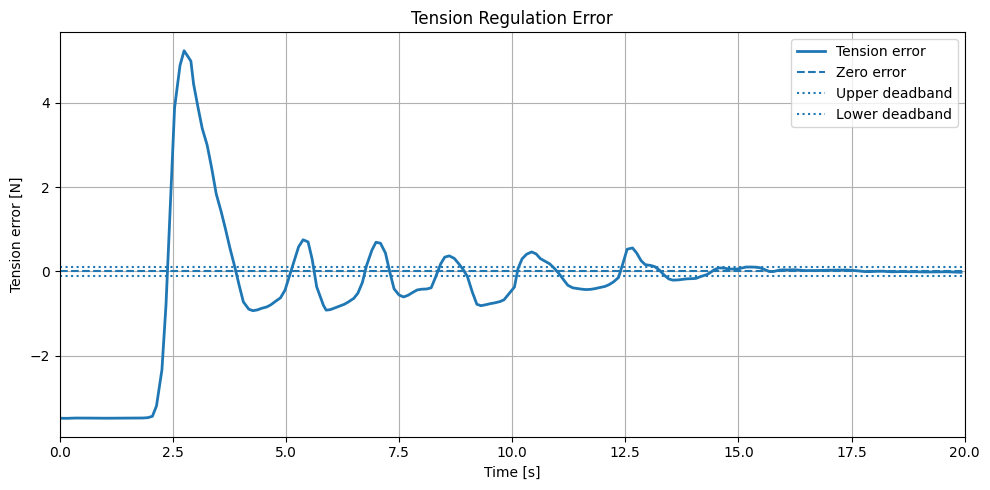
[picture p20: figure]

Target tension: 3.5 N
Final 5 s window:
Mean tension: 3.52 N
MAE: 0.025 N (0.72%)
RMSE: 0.036 N (1.03%)

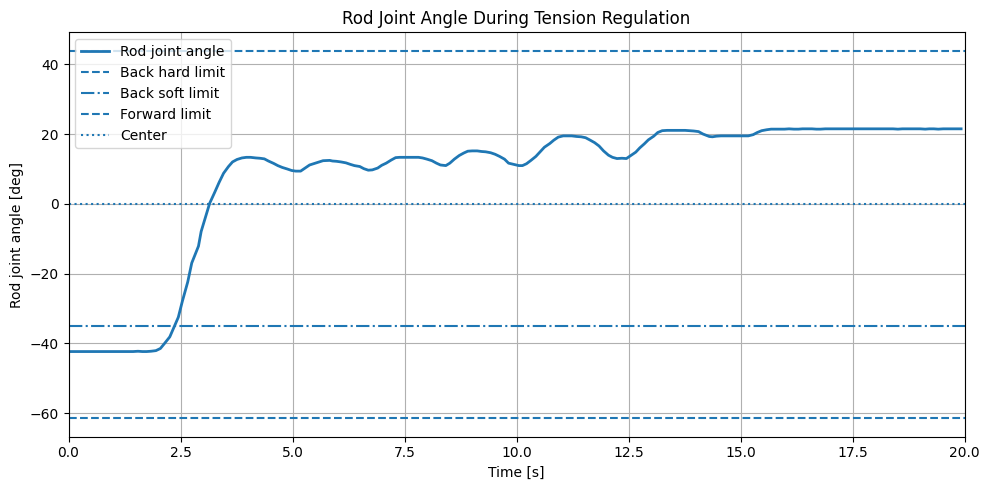
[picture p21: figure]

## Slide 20

Future Developments

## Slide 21

In truth, the fishing problem is extremely control rich in my opinion
I will try to convey this nuance

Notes: upon further understanding of the problem, it became clear that this apparently simple problem has incredibly deep and rich control ideas embedded within it

## Algorithmic extensions

2D Tension control
Planarized fish movement adds sensing complexity
- Our load sensor is 1D
  - instead of direct linear force/tension estimation relation, need to be aware of tension vector
  - use load sensor info and kinematic state (encoders) -> kinematic variation
OR
  - (use joint torque/position and load cell) -> sensor fusion, extended kalman filter
- complicates control problem
  - nonlinear coupling dynamics
  - orthogonal subspaces (hybrid control)
Hybrid control?
- Force Control (Admittance) along the axis of the fishing line to maintain perfect tension
- Rigid Position Control in the perpendicular axes
- Motivation: stiffness to reorient rod optimally, while allowing compliance on the force adaptive pulling axis

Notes: for one if we consider the planarized case and consider our limited sensing framework, we need to employ sensor fusion techniques to ensure optimal tension estimation

on the control front, hybrid control may be optimal and worth testing to allow admittance in the tension management axis and stiffness in perpendicular axes

## Algorithmic extensions

More robust state switching capability
Current Finite State machine uses force thresholding, which is very “chattery”
Solutions/Considerations:
- Hysteresis (anisotropic force thresholds for entering and exiting a state) & Debouncing (time based thresholding/conditioning) to limit false/rapid triggering
- Bumpless transfer
  - smoothing filters
  - transition states?
- Tension break detection (rate of force change) and funnel synthesis (bound tracking error)
  - Drops into a safe, heavily damped recovery ‘funnel’ in case of line break preventing the robotic arm from violently whipping backward and breaking motors
  - funnel synthesis concept also useful for control regain
- Admittance Control hardware implementation (gain scheduling)

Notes: another crucial facet of the control problem is state switching capability

discrete states are embedded within the fishing problem

discrete control switching is incredibly control rich

transition from fish searching to hook set.
switching from having fish to losing tension.
how do we ensure stable control behavior within our discrete state switching

funnel synthesis to bound the control behavior

## Algorithmic extensions

Noise reduction
Probabilistic state estimation (HMM, Bayesian filter)
[important in RL, partial observability/limited info scenarios]
  - Frequency and derivative of the force to distinguish between fake disturbances (boat rocking, snag on seaweed) or an actual fish
OR
Just use vision (unless there are partial observability concerns)

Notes: another important facet is state switching capability
transition from fish searching to hook set.
switching from having fish to losing tension.
how do we ensure stable control behavior within our discrete state switching

## Algorithmic extensions (AI)

Adaptive neural network
Augmentation of control loop with an adaptive neural network feedforward term that learns the stochastic frequency of the fish's pulling behavior, effectively predicting the required q_d before the tension error grows too large.
Sim-to-real: Using the simulation as an AI training tool to optimize fish tensioning behavior.
- Direct RL: neural network
- Layered RL: controller parameter tweaking
- sim pipeline can also be used for adaptive control tuning without AI

## Hardware Developments

Redundantly actuated serial joint
- Emulate rod compliance with active control capability?
- Macro-micro manipulator structure
  - heavy base joint handle low-frequency, high-amplitude positioning (like tracking boat's movement)
  - A smaller, redundantly actuated serial joint near the tip can be tuned with a much higher control loop frequency to handle high-frequency stochastic disturbances
  - inertial decoupling: torque efficiency, jerky movements doesn’t cause heavy base motor to respond
- Null space optimization
  - infinite joint configs.
  - initiate secondary optimization objectives (torque minimization)
- Dynamic impedance shaping
  - redundant motor acts as dynamically tunable physical stiffness unit that adheres to control needs

## Hardware Developments

A compliant segment added to the end of the rod
- tune stiffness characteristics
- mechanical LPF, dealing with incredibly jerky fish motion in true fishing scenarios
- bumpless transfer stabilization (state transitions), reduce risky torque spikes

## Hardware testing rig

- Actuatable object to mimic a fish that has planarized movement capabilities to perform varied experiments on our hardware system and its accompanying controller design

## Practical Additions

Bringing the product to ‘market’
- Tensioning reel mechanism
- actuated hooking system

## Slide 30

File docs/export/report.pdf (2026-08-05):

# Autonomous Robotic Fishing Line Tension Regulation Using Admittance Control

Nathan Ge
Dept. of MAE
UCLA
Los Angeles, CA, USA

Chaoyi Hu
Dept. of MAE
UCLA
Los Angeles, CA, USA

Julie Nguyen
Dept. of MAE
UCLA
Los Angeles, CA, USA

Xiang Zhou
Dept. of MAE
UCLA
Los Angeles, CA, USA

Abstract—This paper presents an autonomous robotic fishing system focused on post hook-set tension regulation as a force control problem. After a fish is hooked, maintaining line tension requires balancing overpulling, which risks snapping the line, against underpulling, which can lose the fish. Our platform is a one degree-of-freedom robotic rod that measures fishing line tension with a load sensor and uses an admittance controller to convert tension feedback into rod pitch motion. The control architecture combines tension-based regulation with position compensation and an engagement supervisor that manages transitions between idle, active control, and recovery states. We implement the system in a ROS2 software stack and validate it first in MuJoCo simulation with a repeatable fish-like disturbance, then on hardware with manual line tension trials. Simulation and hardware experiments show that the robot responds intelligently to changing line tension rather than applying fixed motor commands. This work demonstrates a practical foundation for sensordriven tension regulation in robotic fishing and motivates future extensions to multi-DOF systems, improved state switching, and more complete autonomous fishing pipelines.
Index Terms—tension regulation, admittance control, force control, robotic fishing, ROS2
I. OVERVIEW

This project explores the potential of autonomous robotic fishing framework. To carry the problem into an engineering lens to build a technical framework around, we centered our robot’s function on the fishing line tension aspect of the fishing pipeline which is modelled as a force control problem. Tension regulation is fundamentally characterized by the balance of overpulling which risks the line snapping and underpulling which can lose the fish. Good anglers will respond by dynamically adjusting the orientation of the rod with intuition and feel, keeping the line tension in a safe zone. The robot will perform this balancing act intelligently with sensor feedback and precise motor control.
Similar robotic fishing systems have been explored in previous projects. AlYaseen et al. developed an autonomous fishing rod that can detect fish bites, pull the line, and stop the motor when high resistance is detected to avoid cutting the line [1]. This is closely related to our project because both systems use the fishing-line force as an important feedback signal. Another robotic fishing pole project used an Arduinocontrolled mechanical system to cast and reel automatically through smartphone or computer control [2]. These examples show that fishing is a suitable application for automation and robotic actuation.
Fishing has also been studied as a force-feedback and haptic simulation problem. The Stanford CHARM Lab developed a haptic fishing robot/simulator to create realistic force feedback for the user [3]. This supports the motivation of our project because the key part of the fishing experience is not only moving the rod, but also reacting to the changing resistance from the fish. Our project extends this idea by using a physical robotic rod and an admittance controller to convert measured tension into rod motion.
The resultant robot platform is a 1 DOF robotic fishing system to control line tension following the hook set fishing phase. The robot employs sensor-based feedback control to manage tension regulation and disturbance rejection. The tension in the fishing line is detected by a load sensor, and the robot controls the rod pitch angle based on the error of the detected tension. The control system logic was modeled and solidified in simulation as a tethered robot in which the fish-like load is an external disturbance via the line. The project also creates a foundation for future work on more realistic multi-DOF fishing robots or autonomous fishing mechanisms.

II. CONTROL OBJECTIVES
To carry the problem into an engineering lens to build a technical framework around, fishing can be characterized by three discrete modes: fish discovery (pre hook-set), tension regulation (post hook-set), and reeling.
Fish discovery describes the phase in which the fishing line is ‘cold’ and waiting for a fish to bite. The controller looks for a disturbance signal to indicate fish interest. A jigging action that mimics live bait may be used in this phase to increase fish hooking probability. This phase also includes holes/gaps in tension sensing caused by a fish already hooked on that escapes the jurisdiction of the control domain. Algorithms/action routines may be employed to restore control over the fish.
Looking past fish discovery is the tension regulation stage, the project’s primary control objective, which centers on maintaining tension through the fishing line. The general control structure involves a physical load sensor that approximates the force through the line, and control algorithms that take this information to modulate the tension estimation data. Tension accommodation lends itself naturally to admittance control or some sort of force regulation control methodology, both of which became primary control methods of exploration for this project. Key concepts/considerations include: Tension regulation, Virtual mass-spring-damper (MSD) admittance loops, and Highly stochastic loads handling.
An additional reeling component may be added to successfully bring the fish to the desired endpoint. Reeling will also require additional hardware to pull the string inward. This would complicate the load sensing packaging and add mechanical complexity that comes with a reeling system. This particular system was not heavily pursued in our research, leaving it an avenue of future development.

III. METHODS

A. Hardware


(a) Physical robot.

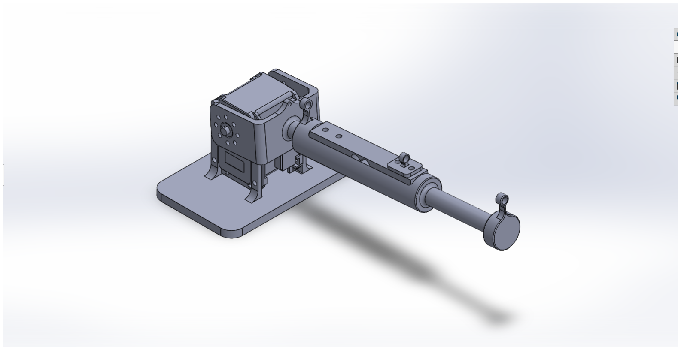
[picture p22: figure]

(b) CAD of robot.

Fig. 1: Robot hardware and corresponding CAD assembly.

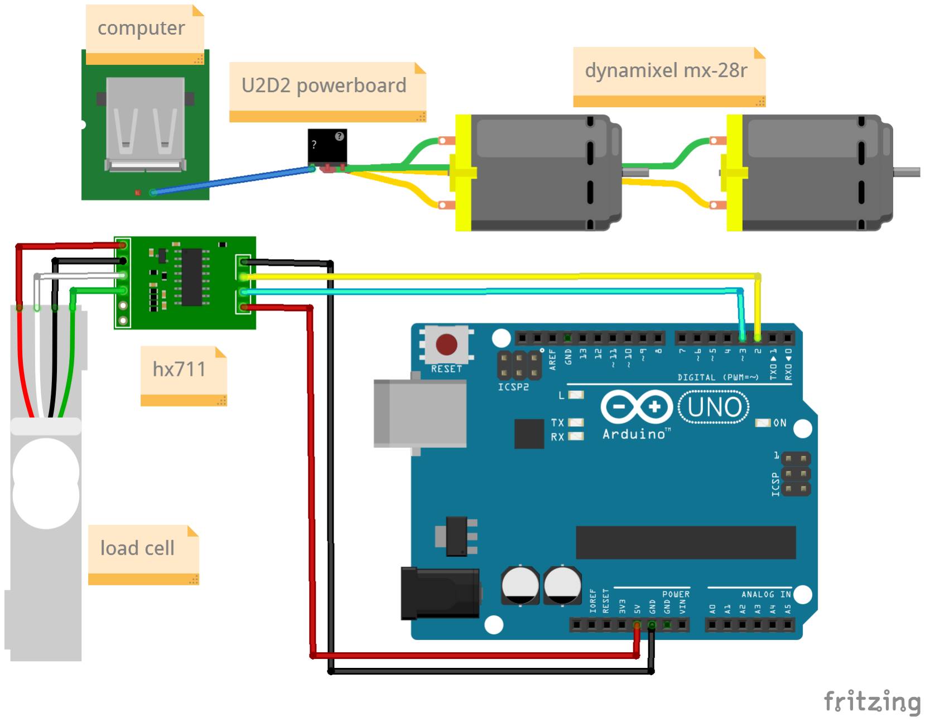
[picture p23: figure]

Fig. 2: Wiring diagram.

B. Mathematical Formulation
1) System Definitions: Let the 2-DOF robotic fishing platform be modeled as a spherical manipulator. We define the state variables and physical parameters as follows:
- q1: The yaw angle of the base around the global Z-axis.
- q2: The pitch angle of the rod relative to the horizontal XY plane.
- L: The fixed length of the fishing rod from the pitch joint to the tip.
- h: The vertical height offset of the pitch joint from the ground.
2) Forward Kinematics: The forward kinematics map the joint space (q1, q2) to the Cartesian task space (x, y, z) of the rod tip. By projecting the rod length onto the horizontal plane, we obtain the radial distance r = Lcos(q2). Decomposing this radial distance and accounting for the base height yields the position equations:

x = Lcos(q1) cos(q2)
y = Lsin(q1) cos(q2)
z = h + Lsin(q2)
3) Inverse Kinematics: The inverse kinematics determine the required joint angles (q1, q2) to reach a desired target coordinate (x, y, z).
The yaw angle q1 is isolated by taking the ratio of the y and x position equations. To ensure the correct quadrant is selected, the two-argument arctangent function is utilized:

q1 = atan2(y, x)

The pitch angle q2 is found by relating the vertical displacement of the rod tip to the horizontal radial distance from the base, where r =

p
x

2 + y

2:

q2 = atan2(z − h, p
x

2 + y

2)

4) Analytical Jacobian: The analytical Jacobian matrix, J, is required for force control and admittance loops. It relates joint velocities to end-effector velocities and maps external Cartesian forces back to joint torques via the relationship τ = J

T Fext.
The matrix is derived by computing the partial derivatives of the forward kinematic position equations with respect to the joint variables q1 and q2:

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
−Lsin(q1) cos(q2) −Lcos(q1) sin(q2)
Lcos(q1) cos(q2) | −Lsin(q1) sin(q2)
0 | Lcos(q2)

C. Codebase and Simulation
Additional ROS2 code documentation can be found here: fishing bot code documentation. (https://nzge.github.io/fishing-bot/)
Building out the ROS2 codebase such that the control logic interacts seamlessly with MuJoco simulation and hardware control

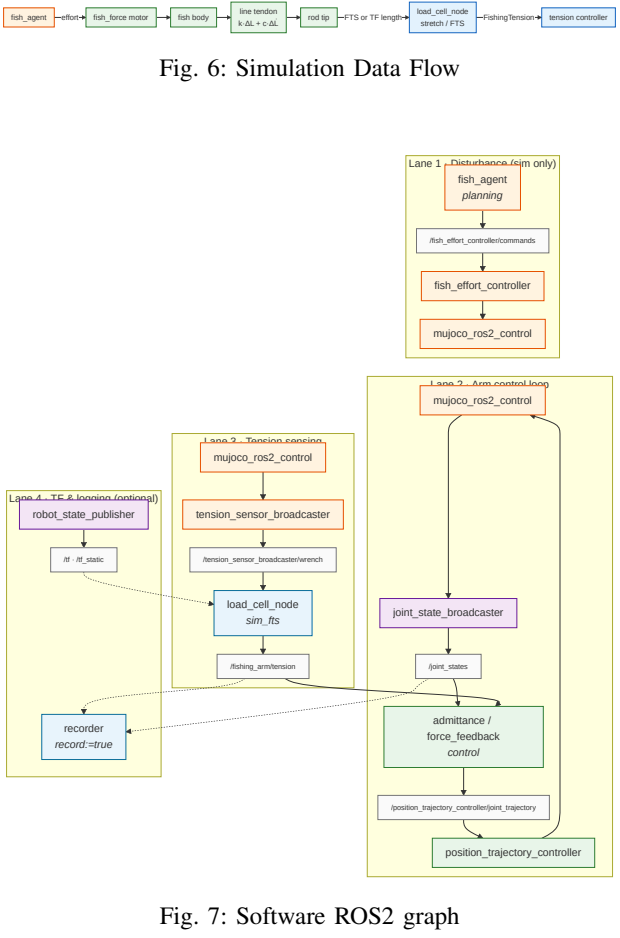
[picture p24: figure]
fish_agent; effort; fish_force motor; fish body; FTS or TF length; FishingTension; line tendon; rod tip; load_cell_node stretch / FTS; tension controller; Fig. 6: Simulation Data Flow; Lane 4 · TF & logging (optional); Lane 3 · Tension sensing; Lane 2 · Arm control loop; Lane 1 · Disturbance (sim only) fish_agent planning; /fish_effort_controller/commands; fish_effort_controller; mujoco_ros2_control; admittance / force_feedback control; /position_trajectory_controller/joint_trajectory; position_trajectory_controller; joint_state_broadcaster; /joint_states; tension_sensor_broadcaster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

TABLE I: Table: Package Descriptions

Package | Description
Bringup | Launch configuration. Can launch simulation or hardware control based on preference.
Description | Mesh and model descriptors.
Control | Tension control package.
Planning | Used to control randomness of ’fish’ behavior. Can be thought of as a fish agent (our distur-bance).
Sensors | Sensor readings and publishing.
Interfaces | Develop protocol for inter-node communication.

tension

fish effort

trajectory

description
URDF · MJCF

bringup
robot.launch.py

interfaces
FishingTension

control

sensors

planning

diagnostics

ros2_control host

robot_state_publisher

Fig. 3: Package Architecture

The following diagram shows the interaction of the selfcontained ROS2 packages and their contributions to the control routine.

t = 0

t ≥ bite_time
hold q_init

hook done
sweep → q_hook

|F| > F_limit

MONITOR | HOOK_SET | REGULATE | |F| safe

ESTOP

Track 3.5 N
Admittance or
force-feedback

Fig. 4: Fishing State Machine

The above diagram shows the transition states enforced by our controller.

/fishing_arm/tension
/joint_trajectory
disturbance | 2-DOF arm | /joint_states load_cell_node
tension ctrl
MONITOR→HOOK→REG
pos_traj_controller

Fig. 5: Control Loop

The above diagram shows the generalized control scheme specific to our ROS2 implementation.

Simulation Pipeline
The behavior of the fish is simulated as a repeatable disturbance for controlled testing. The controllers were tested in a repeatable way with a ROS2 control structure and MuJoCo simulation.

Hardware Control Pipeline
The hardware control flow path slightly varies from the simulation pipeline.
FishingTension | JointTrajectory

rod angle

line load / fish

HX711 | load_cell_node | tension controller | position_traj_controller
line tension | Dynamixel J1·J2

Fig. 8: Data Flow

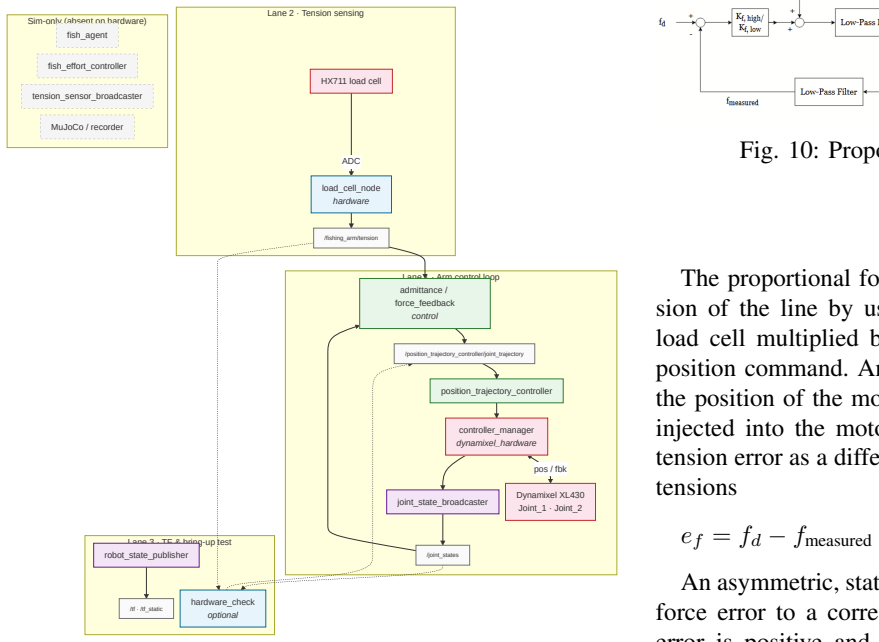
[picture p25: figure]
Lane 3 · TF & bring-up test; Lane 2 · Tension sensing; Lane 1 · Arm control loop; pos / fbk; ADC; Sim-only (absent on hardware) fish_agent; fish_effort_controller; tension_sensor_broadcaster; MuJoCo / recorder; admittance / force_feedback control; /position_trajectory_controller/joint_trajectory; position_trajectory_controller; controller_manager dynamixel_hardware; Dynamixel XL430 Joint_1 · Joint_2; joint_state_broadcaster; /joint_states; HX711 load cell; load_cell_node hardware; /fishing_arm/tension; robot_state_publisher; /tf · /tf_static; hardware_check; optional; tensions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

Fig. 9: Hardware ROS2 Graph

D. Control Architecture

Proportional Force Controller

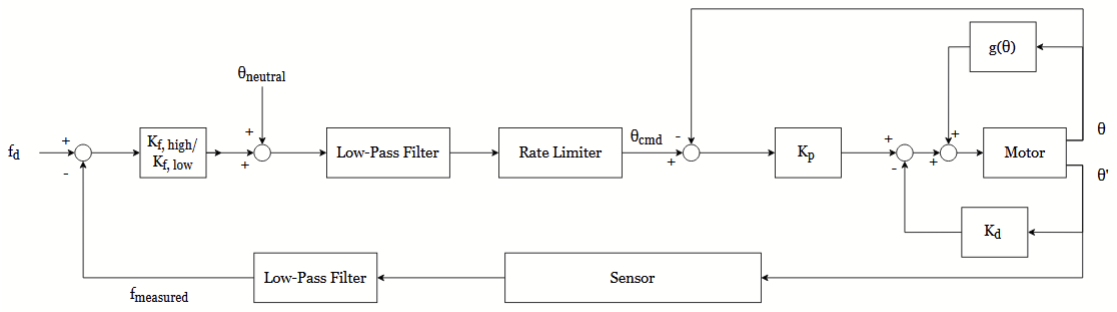
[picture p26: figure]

Fig. 10: Proportional Force Control diagram.

The proportional force controller directly regulates the tension of the line by using the tension error measured by the load cell multiplied by an asymmetric gain to brute-force a position command. An inner PD control is then used to track the position of the motor, and a gravity compensation term is injected into the motor command. The system measures the tension error as a difference between the desired and measured

An asymmetric, state-dependent gain is then used to map the force error to a corresponding position offset. If the tension error is positive and tension is too high, it uses Kf , high, and if the tension is too low, Kf , low is used. Kf , high < Kf , low . This is such that the rod will ‘pull’ harder when the tension is low to pick up the slack of the line. Since the fish is hypothetically faster than the motor, the motor has to aggressively compensate for the lack of tension. However, when the tension is too high, the gain is lower to prevent the robot from slamming forwards to yield to the fish, which would cause the line to immediately go slack. The gains are tuned so that there is a balance between the rod being too stiff and unyielding (low K-value) or too soft and pliant, or over-reactive (high K-value).

The inner loop of the controller is a Proportional-Derivative controller that calculates the effort required to move the motor to the commanded position.

τ = Kp(θcmd − θ) − Kdθ

′ + g(θ)

In this controller Kp(θcmd − θ) acts as a spring to move the motor towards the command position, Kd dictates how aggressively the controller reacts to the rate of change and acts as a brake, and the gravity compensation term, g(θ), is used to counteract the downward pull of gravity. Additionally, low-pass filters and rate limiters are used to prevent high spikes in current and to reject extraneous noise or high-frequency actions.


Fig. 11: Performance Comparison Between Fixed-Angle Control and Proportional Force-Based Tension Control

The results of the MujoCo simulation with Kf , high = 160 and Kf , low = 400 are shown in the figure above. The controlled line remains close to the 1.0N desired target and the controller reports a 69.4% RMS Error Reduction. However there is constant chatter in the rod’s motion. This is concerning since the motor is constantly reversing directions and the system indicates poor high-frequency rejection or smoothing, even despite the filtering. Because of the system’s simplicity and high error reduction, this is the controller chosen for the initial hardware implementation.
Admittance Controller


Fig. 12: Admittance Control diagram.

The admittance controller regulates the tension of the line by simulating a virtual mass-spring-damper system, translating measured force errors into a, dynamic position command. An inner PD control is then used to track the simulated position of the motor, and a gravity compensation term is injected into the motor command. The system governs the target angle, θcmd, by reacting to the tension error, ef , through the virtual physics equation:

Mv
′′
cmd

+ Bvθ′
cmd + Kv(θcmd − θref ) = −J(θ)kf ef

Instead of relying on state-dependent asymmetric gains to manage slack, this architecture relies on sculpting these "virtual physics." The force sensitivity gain, Kf , scales the measured tension error and converts it into a virtual torque using the Jacobian, J(θ). This torque acts upon a virtual mass, Mv, which dictates the inertial resistance of the rod and naturally filters out high-frequency sensor noise. To prevent the rod from oscillating wildly or yielding too quickly, virtual damping, Bv, acts as a physical shock absorber. Finally, a virtual stiffness, Kv, acts as a backbone, providing a restoring force that pulls the rod back to its neutral fighting angle, θref , to prevent the pitch from drifting when the line goes slack. These parameters are tuned to balance a fast, responsive yield against dangerous phase lag or a slow, overly-stiff system. The inner loop of the controller is a Proportional-Derivative controller that calculates the effort required to move the physical motor to the simulated command position.

τ = Kp(θcmd − θ) + Kd(d/dt)(θcmd − θ) + Kgcos(θ)

In this controller, Kp(θcmd − θ) acts as a spring to pull the physical motor towards the virtual target, Kd dictates how aggressively the controller damps the tracking error, and the gravity compensation term, Kgcos(θ), counteracts the downward pull of gravity. Additionally, because the virtual mass and damping mathematically restrict how fast the command signal can accelerate, the system naturally rejects extraneous noise and high-frequency actions without the need for artificial low-pass filters or strict rate limiters.


Fig. 13: Performance Comparison Between Fixed-Angle Control and Admittance-Based Tension Control

The results of the MuJoCo simulation are shown in the figure above. The controlled line yields gracefully to the tension spike, and the controller reports a 42.4% RMS Error Reduction. While the numerical error reduction is lower than the proportional controller due to the inherent phase lag required to accelerate the virtual mass, the rod’s motion is exceptionally smooth and continuous. This is highly advantageous for hardware longevity, as it completely eliminates the jagged, high-frequency motor chatter and constant direction reversals seen in the proportional approach. However, this controller does require a more complex implementation and tuning process.

IV. RESULTS

A. Error Assessment


Fig. 14: Engagement and recovery supervisor state during the hardware trial.

1) Engagement and safety logic: The engagement supervisor was also evaluated during the hardware trial. Before the line tension reached the bite-trigger condition, the controller remained in the IDLE state and commanded zero PWM, preventing the motor from responding to sensor noise or small disturbances. In this implementation, the controller was activated only when the measured tension exceeded 0.8 N for 0.10 s, representing the initial pulling event after a fish is hooked. During active control, a low-tension condition was detected when the measured tension stayed below 1.0 N. If this condition lasted for more than 1.8 s, the supervisor entered the RECOVERY state to avoid continuously pulling against a slack line. Once the measured tension recovered above 2.0 N, the controller returned to active control. The supervisor state plot shows this sequence, with transitions from IDLE to CONTROL, then to RECOVERY, and finally back to CONTROL after the tension recovered.


Fig. 15: Measured tension response during dynamic regulation.
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

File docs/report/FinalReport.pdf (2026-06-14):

# Autonomous Robotic Fishing Line Tension Regulation Using Admittance Control

Nathan Ge
Dept. of MAE
UCLA
Los Angeles, CA, USA

Chaoyi Hu
Dept. of MAE
UCLA
Los Angeles, CA, USA

Julie Nguyen
Dept. of MAE
UCLA
Los Angeles, CA, USA

Xiang Zhou
Dept. of MAE
UCLA
Los Angeles, CA, USA

Abstract—This paper presents an autonomous robotic fishing system focused on post hook-set tension regulation as a force control problem. After a fish is hooked, maintaining line tension requires balancing overpulling, which risks snapping the line, against underpulling, which can lose the fish. Our platform is a one degree-of-freedom robotic rod that measures fishing line tension with a load sensor and uses an admittance controller to convert tension feedback into rod pitch motion. The control architecture combines tension-based regulation with position compensation and an engagement supervisor that manages transitions between idle, active control, and recovery states. We implement the system in a ROS2 software stack and validate it first in MuJoCo simulation with a repeatable fish-like disturbance, then on hardware with manual line tension trials. Simulation and hardware experiments show that the robot responds intelligently to changing line tension rather than applying fixed motor commands. This work demonstrates a practical foundation for sensordriven tension regulation in robotic fishing and motivates future extensions to multi-DOF systems, improved state switching, and more complete autonomous fishing pipelines.
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

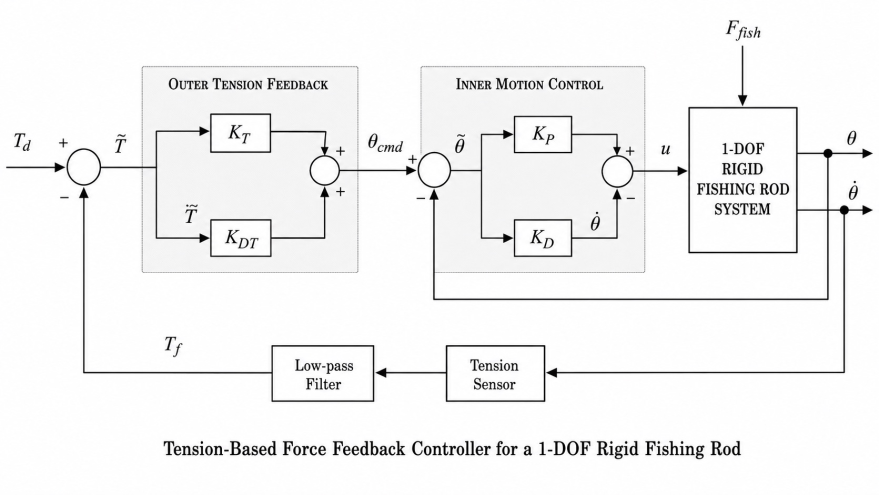
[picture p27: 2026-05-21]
docs/figures/control-diagram1.webp

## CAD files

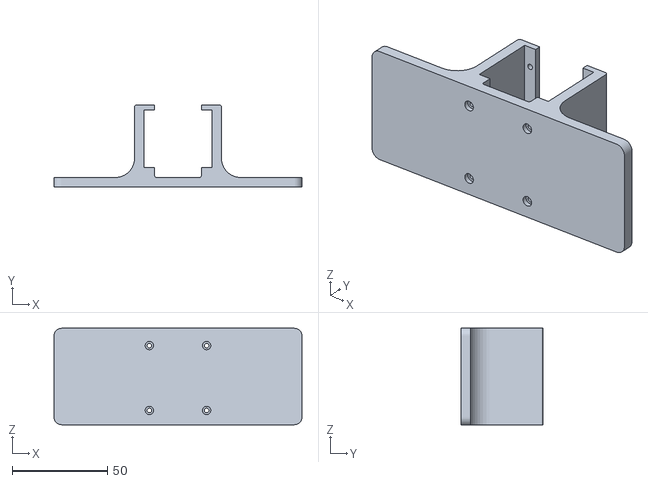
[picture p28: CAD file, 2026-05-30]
CAD/assy2/STL/fishing_assy2 - Part2^fishing_assy2-1.STL
130.0 x 43.0 x 50.6

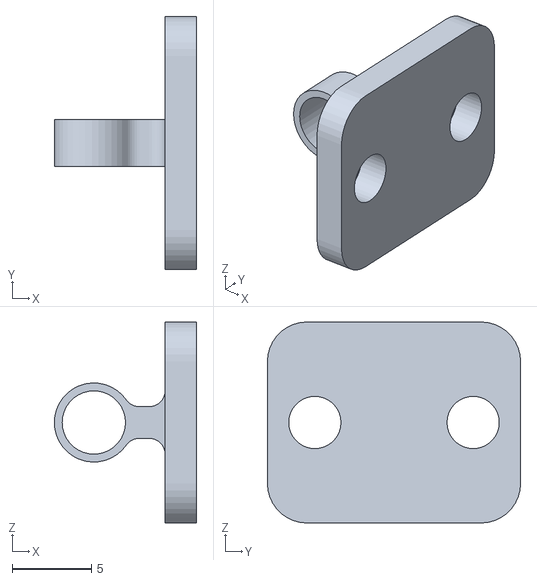
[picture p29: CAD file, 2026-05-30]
CAD/assy2/STL/fishing_assy2 - rod_assy-1 Part1^rod_assy-1.STL
9.00 x 16.0 x 12.7

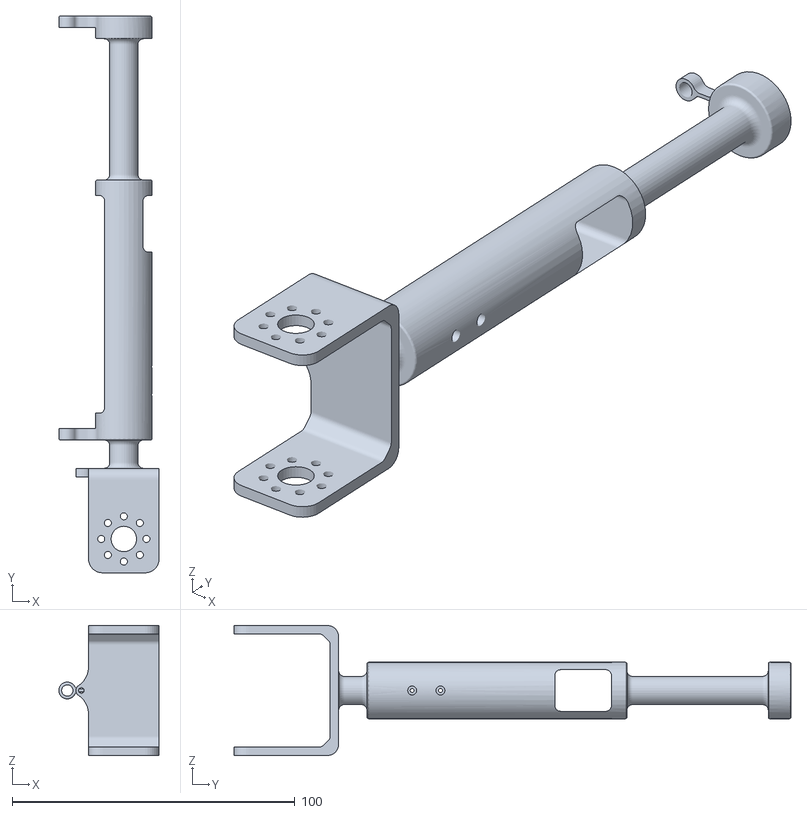
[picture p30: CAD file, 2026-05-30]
CAD/assy2/STL/fishing_assy2 - rod_assy-1 rod-v2-1.STL
35.5 x 197.0 x 46.0

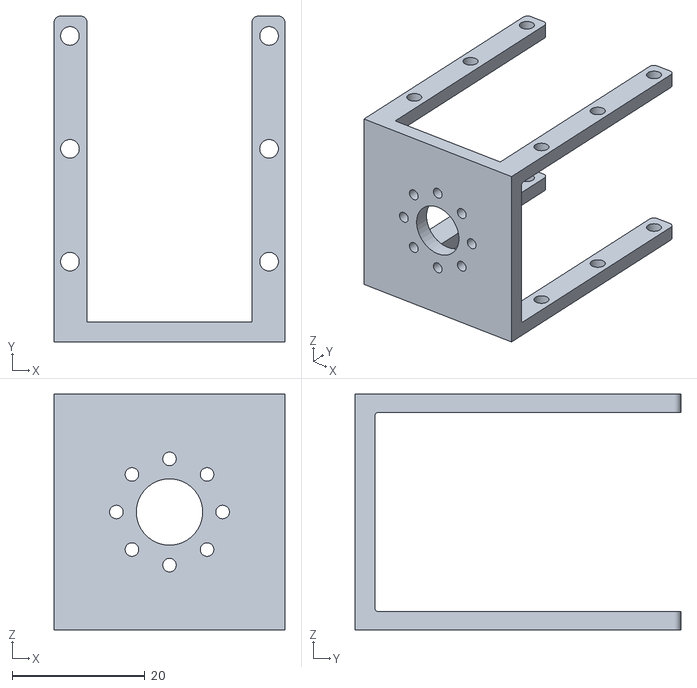
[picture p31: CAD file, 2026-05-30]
CAD/assy2/STL/fishing_assy2 - Part1^fishing_assy2-1.STL
34.8 x 49.1 x 35.5

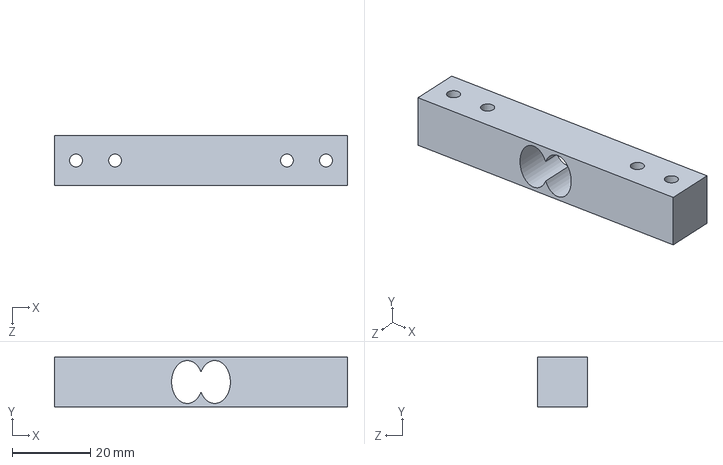
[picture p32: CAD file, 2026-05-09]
CAD/assets/load-cell.SLDPRT
75.0 x 12.7 x 12.7 mm

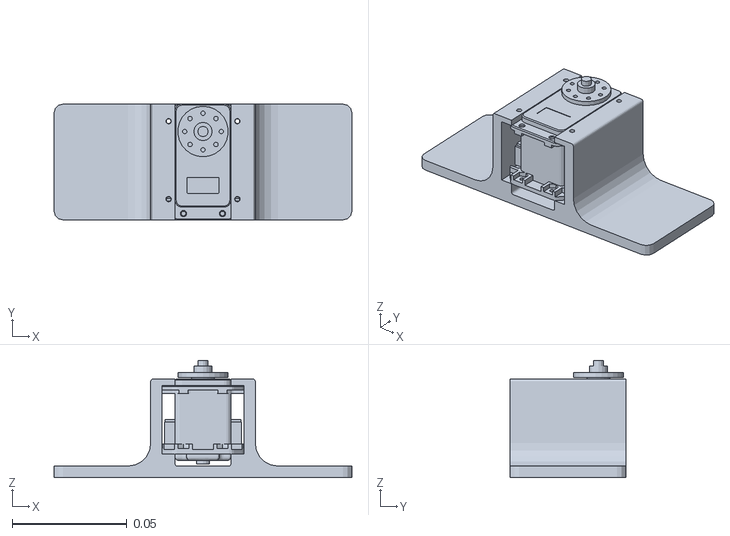
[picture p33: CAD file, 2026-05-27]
CAD/assy2/meshes/base_link.STL
0.13 x 0.0506 x 0.0511

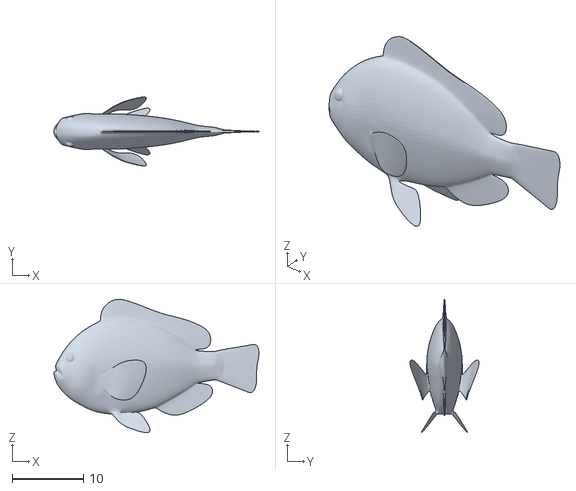
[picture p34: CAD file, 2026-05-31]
software/src/description/meshes/fish.STL
28.7 x 9.69 x 18.7

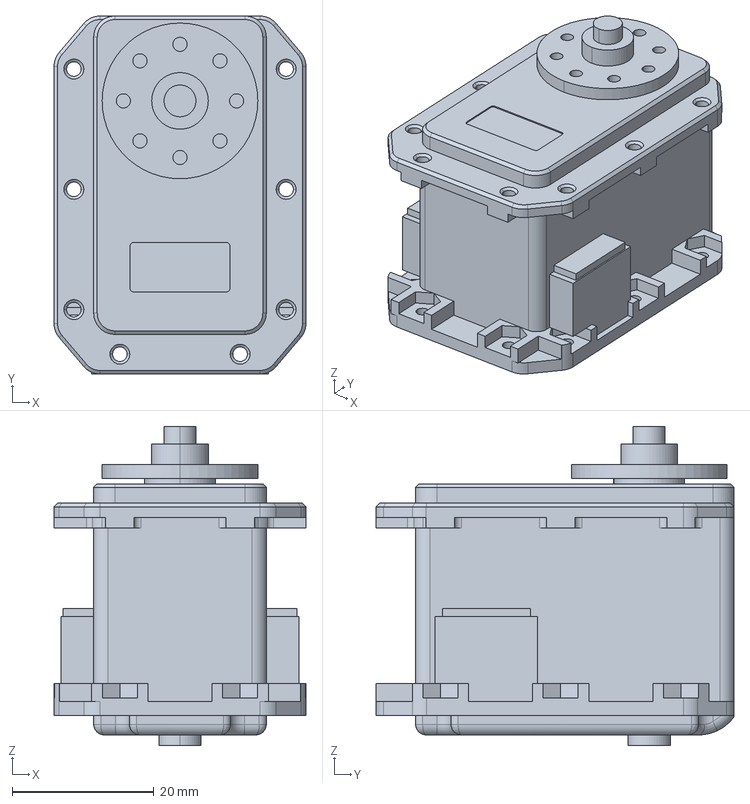
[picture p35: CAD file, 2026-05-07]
CAD/assets/MX-28AT_AR.stp
35.6 x 50.6 x 45.1 mm

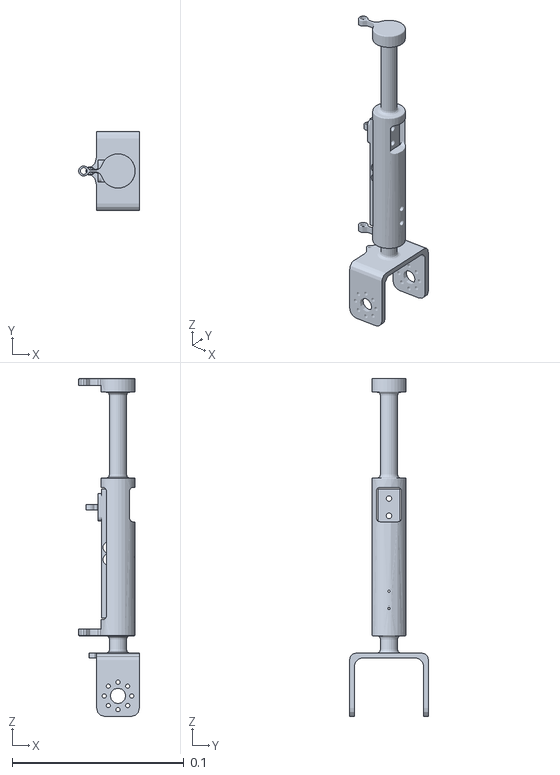
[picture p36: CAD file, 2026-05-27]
CAD/assy2/meshes/Link_2.STL
0.0355 x 0.046 x 0.197

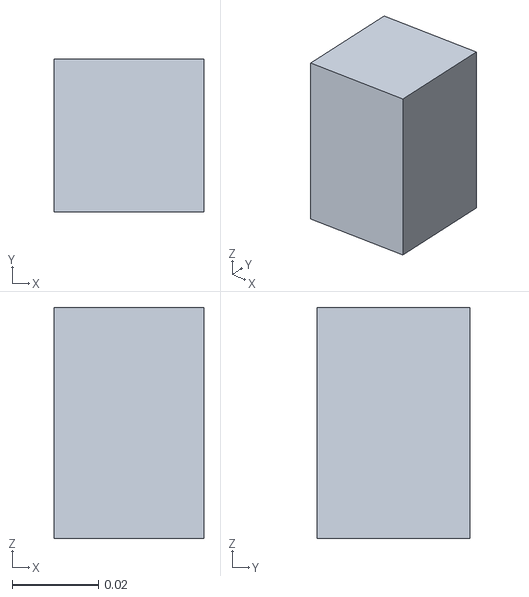
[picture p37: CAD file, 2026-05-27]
software/src/description/meshes/Link_1_collision.STL
0.0348 x 0.0355 x 0.0536

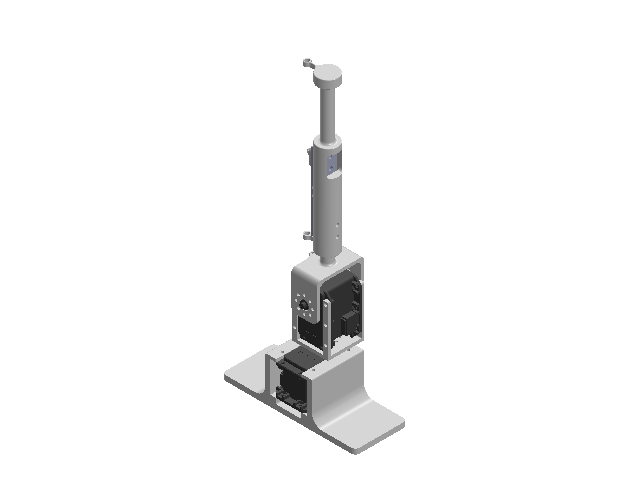
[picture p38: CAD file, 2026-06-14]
CAD/assy2/fishing_assy2.SLDASM
MX-28AT_AR x 2
Part2^fishing_assy2
rod-v2
load-cell
Part1^rod_assy
Part1^fishing_assy2

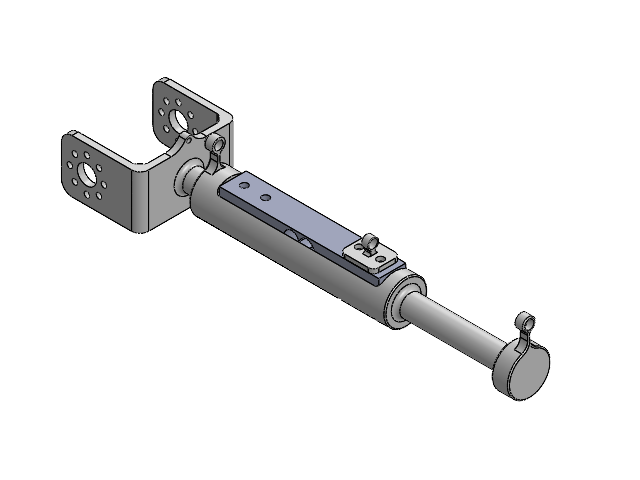
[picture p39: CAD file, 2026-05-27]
CAD/rod_assy.SLDASM
rod-v2
load-cell
Part1^rod_assy

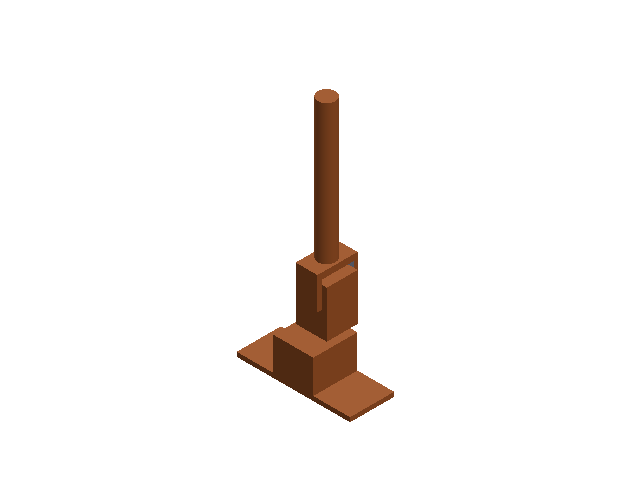
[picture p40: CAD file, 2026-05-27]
CAD/assy2/fishing_assy2_collisional.SLDASM
Base_Collision
Link1_Collision
Link2_Collision

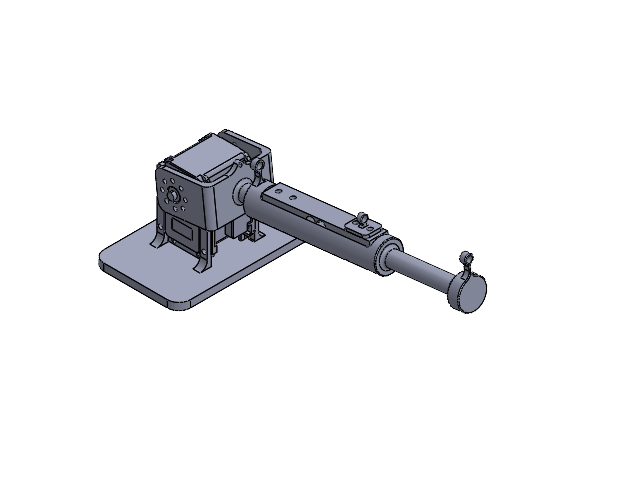
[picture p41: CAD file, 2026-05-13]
CAD/fishing_assy.SLDASM
MX-28AT_AR
rod-v2
load-cell
Part1^rod_assy
Part1^fishing_assy

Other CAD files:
CAD/assy2/fishing_assy2_visual.SLDASM
CAD/assy2/Link1_Collision.SLDPRT
CAD/assy2/Link2_Collision.SLDPRT
CAD/assets/MX-28AT_AR.SLDPRT
CAD/assy2/Base_Collision.SLDPRT
CAD/assy2/meshes/Link_1.STL
CAD/assy2/meshes/Link_2_collision.STL
CAD/assy2/meshes/base_link_collision.STL
CAD/rod-v2.SLDPRT
CAD/rod-v3.SLDPRT
CAD/rod.SLDPRT
software/src/description/meshes/Link_1.STL
software/src/description/meshes/Link_2_collision.STL
software/src/description/meshes/base_link_collision.STL

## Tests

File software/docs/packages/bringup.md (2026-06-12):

# `bringup` — Launch Orchestration

The `bringup` package is the **single entry point** for the entire fishing-arm stack.
It owns no application logic; instead it wires together `ros2_control`, TF, and
delegates to the other packages via `IncludeLaunchDescription`.

**Source:** `software/src/bringup/`  
**Auto-generated tables:** {doc}`../_generated/reference/packages/bringup`

## Role in the stack

`robot.launch.py` is the only launch file most operators need. It:

1. Resolves the **`use_sim`** flag at xacro time, selecting the hardware plugin.
2. Starts **`robot_state_publisher`** (both modes).
3. Starts either **`mujoco_ros2_control`** (sim) or **`controller_manager`** (HW).
4. Spawns ros2_control controllers via **`controller_manager/spawner`** nodes.
5. Includes application launches from `control`, `sensors`, `planning`, and `diagnostics`.

```{mermaid}
flowchart TB
    RL["robot.launch.py"]
    RL --> RSP["robot_state_publisher"]
    RL -->|"use_sim=true"| MJ["mujoco_ros2_control"]
    RL -->|"use_sim=false"| CM["controller_manager"]
    RL --> SP["controller spawners"]
    RL --> CL["control.launch.py"]
    RL --> SL["sensor.launch.py"]
    RL --> FL["fish.launch.py<br/>(sim only)"]
    RL --> DL["diagnostics.launch.py<br/>(record:=true)"]
    RL --> HC["hardware_check<br/>(hardware_check:=true)"]
```

## Launch arguments

| Argument | Default | Effect |
| --- | --- | --- |
| `use_sim` | `true` | MuJoCo simulation vs Dynamixel hardware |
| `headless` | `false` | Hide MuJoCo GUI (sim only) |
| `run_duration` | `0` | Auto-shutdown after N seconds (0 = until Ctrl-C) |
| `record` | `false` | Enable diagnostics recorder + animation (sim) |
| `hardware_check` | `false` | Open-loop motor/sensor test; **disables controller** |
| `controller_type` | `admittance` | `admittance`, `force_feedback`, or `none` |

Full argument list with descriptions is regenerated in the
{doc}`../_generated/reference/packages/bringup` page on every build.

## Sim vs hardware branching

The **`use_sim`** argument is passed into xacro when the URDF is generated:

```bash
xacro fishing-robot.urdf.xacro use_sim:=true headless:=false
```

This swaps the `<hardware>` plugin inside `<ros2_control>` *before* any controller
loads. See {doc}`description` and {doc}`../ros2/index` for the resulting
differences in nodes and topics.

### Controller spawners

These spawners talk to `/controller_manager` and are **identical in both modes**
for the arm controllers:

| Spawner | Controller | Mode |
| --- | --- | --- |
| `joint_state_broadcaster` | Publishes `/joint_states` | both |
| `position_trajectory_controller` | Accepts `JointTrajectory` commands | both |
| `fish_effort_controller` | Forwards fish effort to MuJoCo | **sim only** |
| `tension_sensor_broadcaster` | Publishes rod-tip FTS wrench | **sim only** |

Configuration lives in `config/controllers.yaml`.

### Application delegation

Rather than declaring application nodes inline, `robot.launch.py` delegates:

| Included launch | Package | Condition |
| --- | --- | --- |
| `control.launch.py` | `control` | `unless hardware_check` |
| `sensor.launch.py` | `sensors` | always |
| `fish.launch.py` | `planning` | `if use_sim` |
| `diagnostics.launch.py` | `diagnostics` | `if record` |

The sensor source is set programmatically:

```python
source = 'sim_fts' if use_sim else 'hardware'
```

## Configuration files

### `config/controllers.yaml`

Declares the ros2_control controller types and joint lists. Key entries:

- **`position_trajectory_controller`** — joints `Joint_1`, `Joint_2`; position command interface.
- **`fish_effort_controller`** (sim) — joint `fish_swim`; effort interface for the virtual fish.
- **`tension_sensor_broadcaster`** (sim) — sensor `tension_sensor` → `/tension_sensor_broadcaster/wrench`.

### `config/params.yaml`

Shared tuning for both tension controllers (`admittance_controller` and
`force_feedback_controller` namespaces). Passed to whichever controller node
`control.launch.py` starts. See {doc}`control` for parameter semantics.

## Interactions with other packages

```{list-table}
:header-rows: 1
:widths: 22 78

* - Package
  - Interaction
* - `description`
  - Supplies xacro/URDF processed with `use_sim` and `headless`; MJCF path embedded in URDF for sim.
* - `control`
  - Included via `control.launch.py`; receives `controller_type` launch arg.
* - `sensors`
  - Included via `sensor.launch.py`; receives `source` launch arg derived from `use_sim`.
* - `planning`
  - Included only in sim; fish disturbance drives `fish_effort_controller`.
* - `diagnostics`
  - `recorder` when `record:=true`; `hardware_check` when `hardware_check:=true`.
* - `interfaces`
  - Indirect — all app nodes use `FishingTension` published by sensors, consumed by control.
```

## Typical launch commands

```bash
# Default simulation
ros2 launch bringup robot.launch.py

# Headless sim with 30 s recording
ros2 launch bringup robot.launch.py headless:=true record:=true run_duration:=30

# Hardware with Chaoyi controller
ros2 launch bringup robot.launch.py use_sim:=false controller_type:=force_feedback

# Pre-flight open-loop check (works in sim or HW)
ros2 launch bringup robot.launch.py hardware_check:=true
```

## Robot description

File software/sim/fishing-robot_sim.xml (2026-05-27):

<mujoco model="fishing_robot">
  <compiler angle="radian" coordinate="local" meshdir="../meshes"/>

  <asset>
    <mesh name="base_link_collision" file="base_link_collision.STL"/>
    <mesh name="Link_1_collision" file="Link_1_collision.STL"/>
    <mesh name="Link_2_collision" file="Link_2_collision.STL"/>
    
    <mesh name="base_link_visual" file="base_link.STL"/>
    <mesh name="Link_1_visual" file="Link_1.STL"/>
    <mesh name="Link_2_visual" file="Link_2.STL"/>
  </asset>

  <worldbody>
    <body name="reel_anchor" pos="0 0 0">
      <site name="reel_site" pos="0 -1.0 0" size="0.01"/>
    </body>

    <body name="base_link" pos="0 0 0">
      <geom type="mesh" mesh="base_link_collision"/>
      <geom type="mesh" mesh="base_link_visual" rgba="0.75 0.75 0.75 1" contype="0" conaffinity="0"/>

      <body name="Link_1" pos="0 0 0.02335">
        <inertial pos="1.98733e-05 -0.000248211 0.0252855" quat="0.997703 0.0677224 -0.00113881 0.00132904" mass="0.0497088" diaginertia="1.48174e-05 1.25845e-05 9.64573e-06"/>
        <joint name="Joint_1" pos="0 0 0" axis="0 0 1" range="-3.1416 3.1416" actuatorfrcrange="-2.5 2.5"/>
        <geom type="mesh" mesh="Link_1_collision"/>
        <geom type="mesh" mesh="Link_1_visual" rgba="0.75 0.75 0.75 1" contype="0" conaffinity="0"/>

        <body name="Link_2" pos="0 -0.02335 0.03875">
          <inertial pos="-0.000376763 0.02285 0.0758976" quat="1 0 -0.000462491 0" mass="0.0374845" diaginertia="9.81279e-05 9.58498e-05 4.42178e-06"/>
          <joint name="Joint_2" pos="0 0 0" axis="0 1 0" range="-3.1416 3.1416" actuatorfrcrange="-2.5 2.5"/>
          <geom type="mesh" mesh="Link_2_collision"/>
          <geom type="mesh" mesh="Link_2_visual" rgba="0.75 0.75 0.75 1" contype="0" conaffinity="0"/>
          
          <site name="rod_tip_site" pos="0 0 0.19" size="0.01"/> 
        </body>
      </body>
    </body>
  </worldbody>

  <!-- tendon>
    <spatial name="fishing_line" stiffness="100" damping="1">
      <site site="reel_site" />
      <site site="rod_tip_site" />
    </spatial>
  </tendon -->

  <sensor>
    <force name="tension_sensor" site="rod_tip_site" />
  </sensor>

  

  <keyframe>
    <key name="starting_pose" qpos="1.57 2.61"/>
  </keyframe>

</mujoco>

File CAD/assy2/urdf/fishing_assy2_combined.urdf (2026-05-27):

<?xml version="1.0" encoding="utf-8"?>
<!-- This URDF was automatically created by SolidWorks to URDF Exporter! Originally created by Stephen Brawner (brawner@gmail.com) 
     Commit Version: 1.6.0-4-g7f85cfe  Build Version: 1.6.7995.38578
     For more information, please see http://wiki.ros.org/sw_urdf_exporter -->
<robot name="fishing_assy2_combined">
  <link name="base_link">
    <inertial>
      <origin xyz="9.64494158785974E-06 -0.0124364350363364 -0.00800838743932182" rpy="0 0 0" />
      <mass value="0.10242435780476" />
      <inertia ixx="3.44658980710862E-05" ixy="1.15685827535353E-08" ixz="-4.74633377970236E-09" iyy="7.35797461812803E-05" iyz="-3.93838381066106E-07" izz="7.91602302077541E-05" />
    </inertial>
    <visual>
      <origin xyz="0 0 0" rpy="0 0 0" />
      <geometry>
        <mesh filename="package://fishing_assy2_combined/meshes/base_link.STL" />
      </geometry>
      <material name="">
        <color rgba="0.752941176470588 0.752941176470588 0.752941176470588 1" />
      </material>
    </visual>
    <collision>
      <origin xyz="0 0 0" rpy="0 0 0" />
      <geometry>
        <mesh filename="package://fishing_assy2_combined/meshes/base_link.STL" />
      </geometry>
    </collision>
  </link>
  <link name="Link_1">
    <inertial>
      <origin xyz="1.98732975738997E-05 -0.000248210549754878 0.025285547707494" rpy="0 0 0" />
      <mass value="0.0497087584246774" />
      <inertia ixx="1.48173848978349E-05" ixy="4.74633377970562E-09" ixz="1.15685827535328E-08" iyy="1.25308227827468E-05" iyz="3.93501789908991E-07" izz="9.69942781916457E-06" />
    </inertial>
    <visual>
      <origin xyz="0 0 0" rpy="0 0 0" />
      <geometry>
        <mesh filename="package://fishing_assy2_combined/meshes/Link_1.STL" />
      </geometry>
      <material name="">
        <color rgba="0.752941176470588 0.752941176470588 0.752941176470588 1" />
      </material>
    </visual>
    <collision>
      <origin xyz="0 0 0" rpy="0 0 0" />
      <geometry>
        <mesh filename="package://fishing_assy2_combined/meshes/Link_1.STL" />
      </geometry>
    </collision>
  </link>
  <joint name="Joint_1" type="revolute">
    <origin xyz="0 0 0.02335" rpy="0 0 0" />
    <parent link="base_link" />
    <child link="Link_1" />
    <axis xyz="0 0 1" />
    <limit lower="-3.1416" upper="3.1416" effort="2.5" velocity="5.76" />
  </joint>
  <link name="Link_2">
    <inertial>
      <origin xyz="-0.000376762904282731 0.0228500014053185 0.0758975605697149" rpy="0 0 0" />
      <mass value="0.0374844556058819" />
      <inertia ixx="9.81277949436277E-05" ixy="4.17865645290201E-13" ixz="8.66764648076052E-08" iyy="9.58497532082512E-05" iyz="1.55605785755593E-12" izz="4.42186013584717E-06" />
    </inertial>
    <visual>
      <origin xyz="0 0 0" rpy="0 0 0" />
      <geometry>
        <mesh filename="package://fishing_assy2_combined/meshes/Link_2.STL" />
      </geometry>
      <material name="">
        <color rgba="0.752941176470588 0.752941176470588 0.752941176470588 1" />
      </material>
    </visual>
    <collision>
      <origin xyz="0 0 0" rpy="0 0 0" />
      <geometry>
        <mesh filename="package://fishing_assy2_combined/meshes/Link_2.STL" />
      </geometry>
    </collision>
  </link>
  <joint name="Joint_2" type="revolute">
    <origin xyz="0 -0.02335 0.03875" rpy="0 0 0" />
    <parent link="Link_1" />
    <child link="Link_2" />
    <axis xyz="0 1 0" />
    <limit lower="-3.1416" upper="3.1416" effort="2.5" velocity="5.76" />
  </joint>
</robot>

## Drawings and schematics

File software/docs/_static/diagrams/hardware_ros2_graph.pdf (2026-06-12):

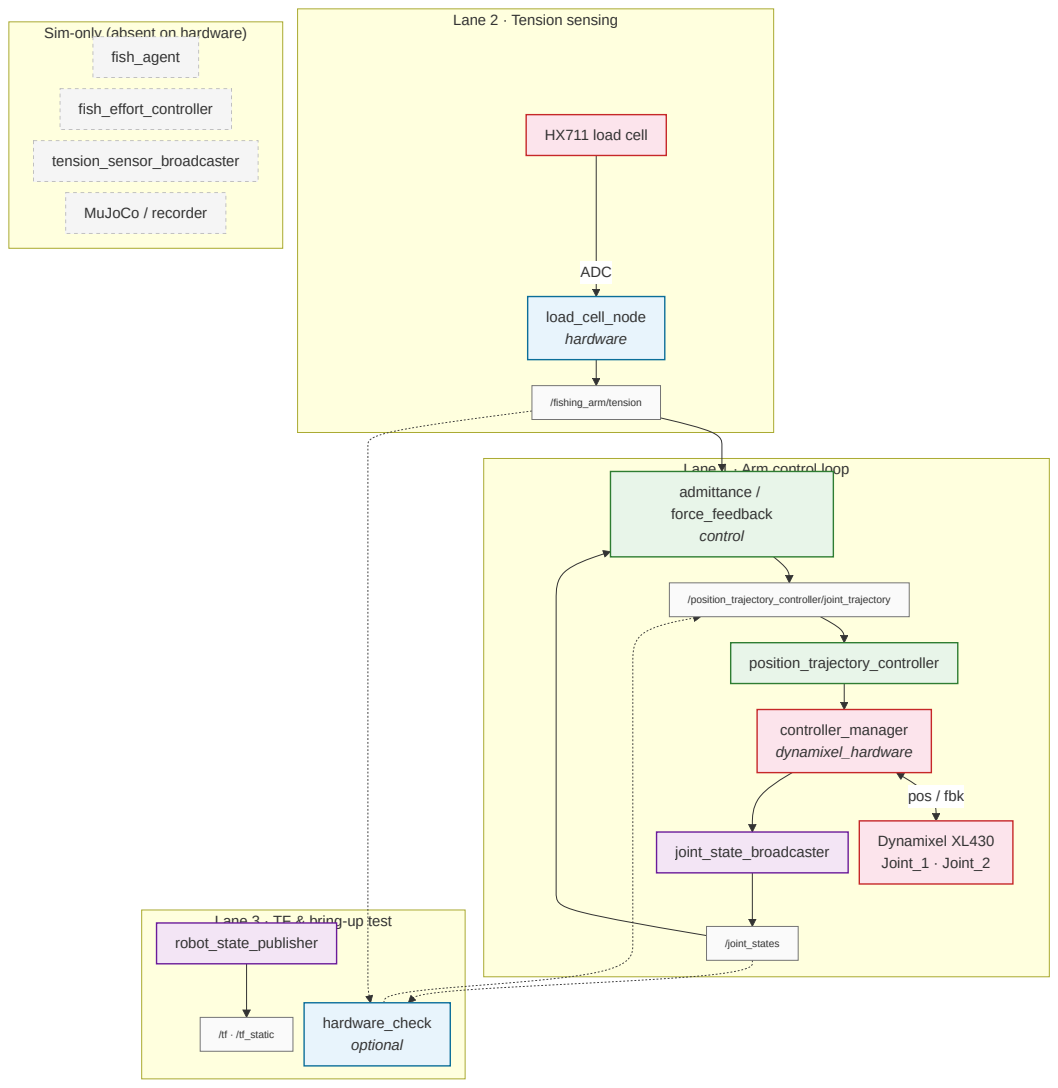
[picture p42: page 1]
pos / fbk; ADC; fish_agent; fish_effort_controller; tension_sensor_broadcaster; MuJoCo / recorder; /position_trajectory_controller/joint_trajectory; position_trajectory_controller; controller_manager dynamixel_hardware; Dynamixel XL430 Joint_1 · Joint_2; joint_state_broadcaster; /joint_states; HX711 load cell; load_cell_node hardware; /fishing_arm/tension; /tf · /tf_static; hardware_check optional

Lane 2 · Tension sensing

Sim-only (absent on hardware)

Lane 1 · Arm control loop
admittance /
force_feedback
control

Lane 3 · TF & bring-up test
robot_state_publisher

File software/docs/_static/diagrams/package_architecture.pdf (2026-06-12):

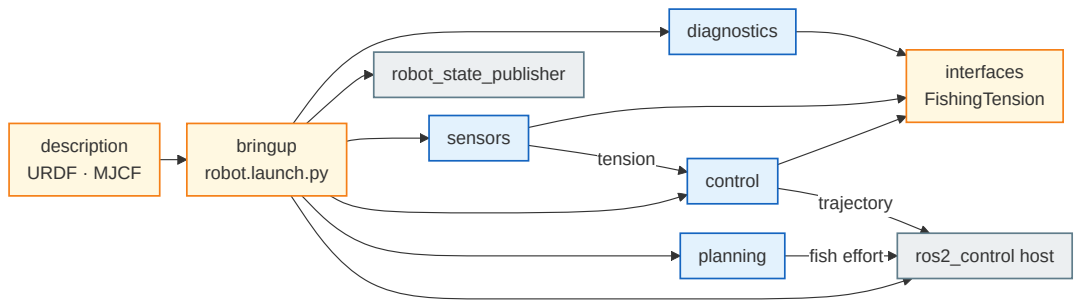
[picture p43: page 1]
tension; fish effort; trajectory; description URDF · MJCF; interfaces FishingTension; control; sensors; planning; diagnostics; ros2_control host; robot_state_publisher

bringup
robot.launch.py

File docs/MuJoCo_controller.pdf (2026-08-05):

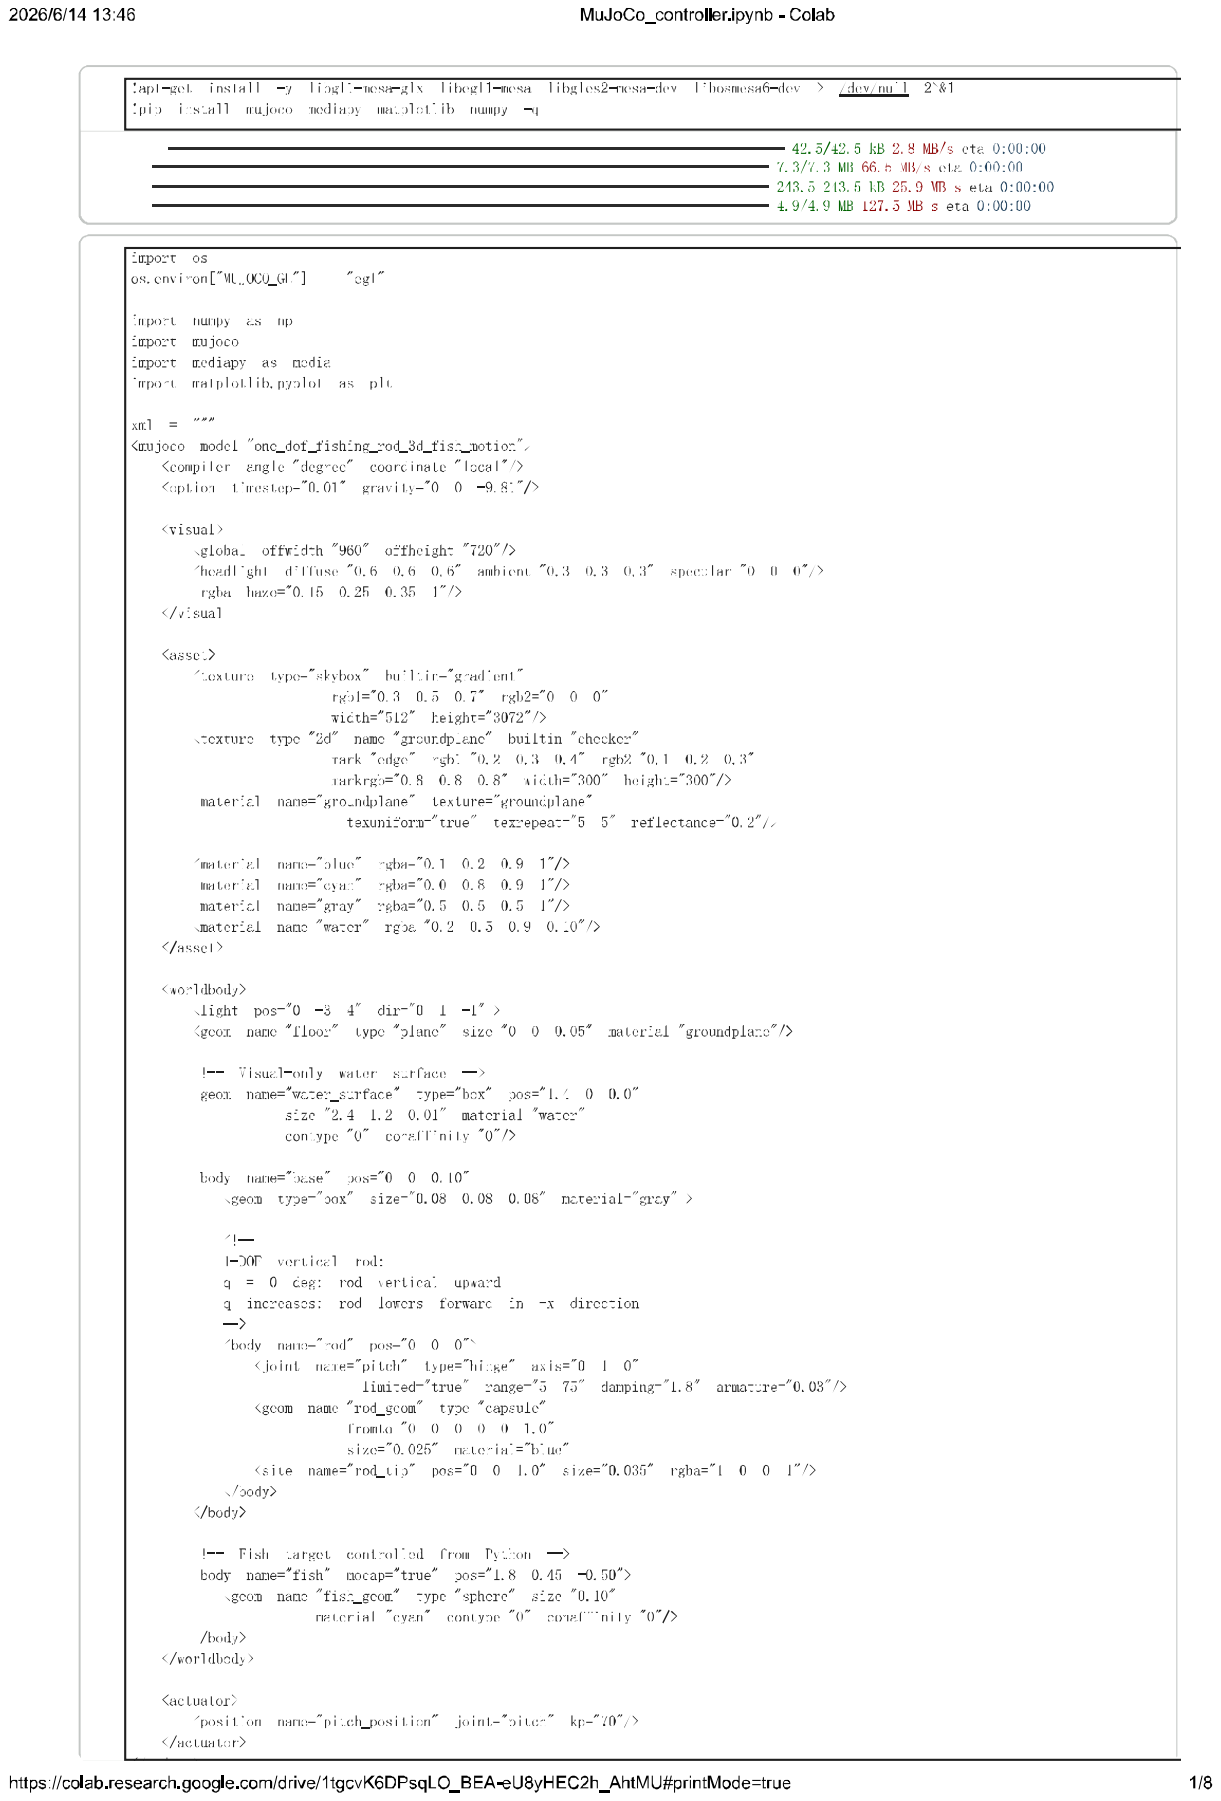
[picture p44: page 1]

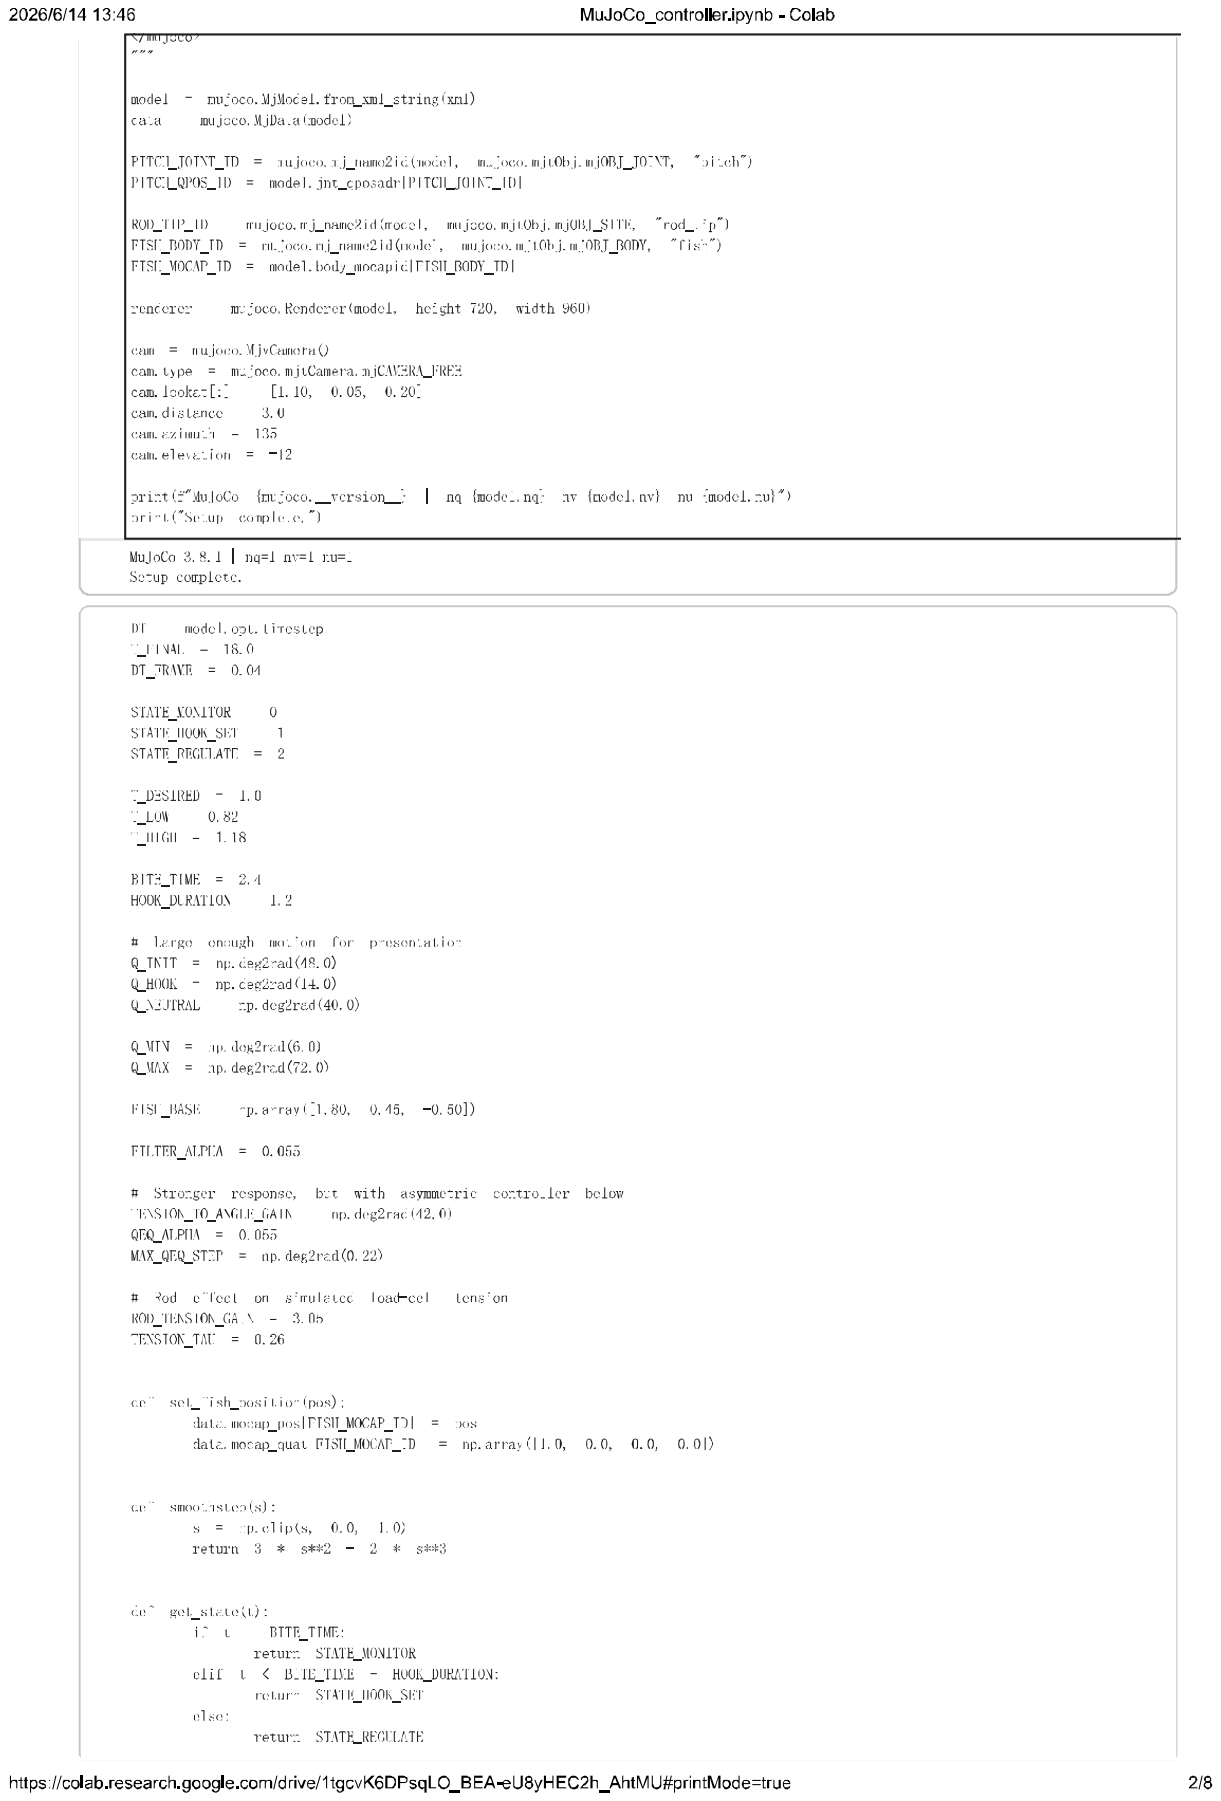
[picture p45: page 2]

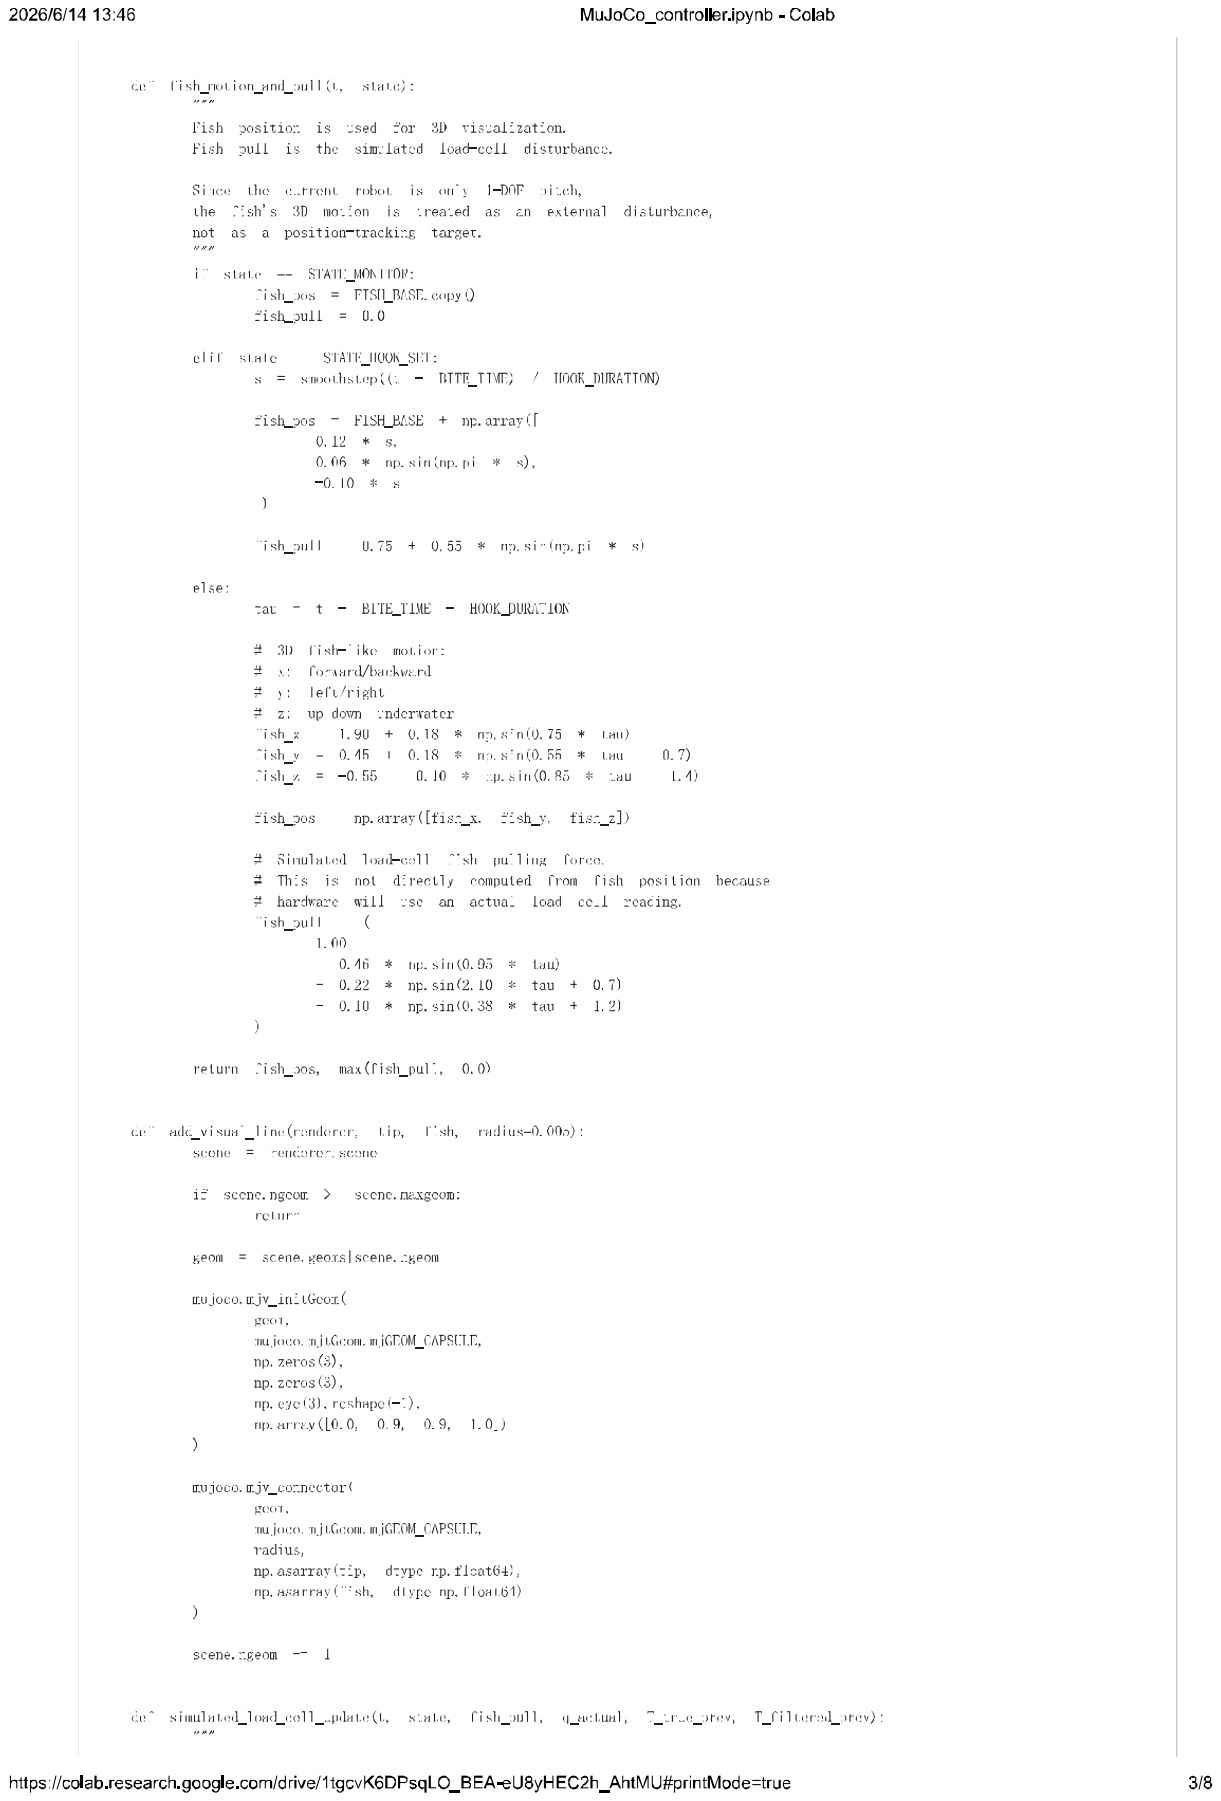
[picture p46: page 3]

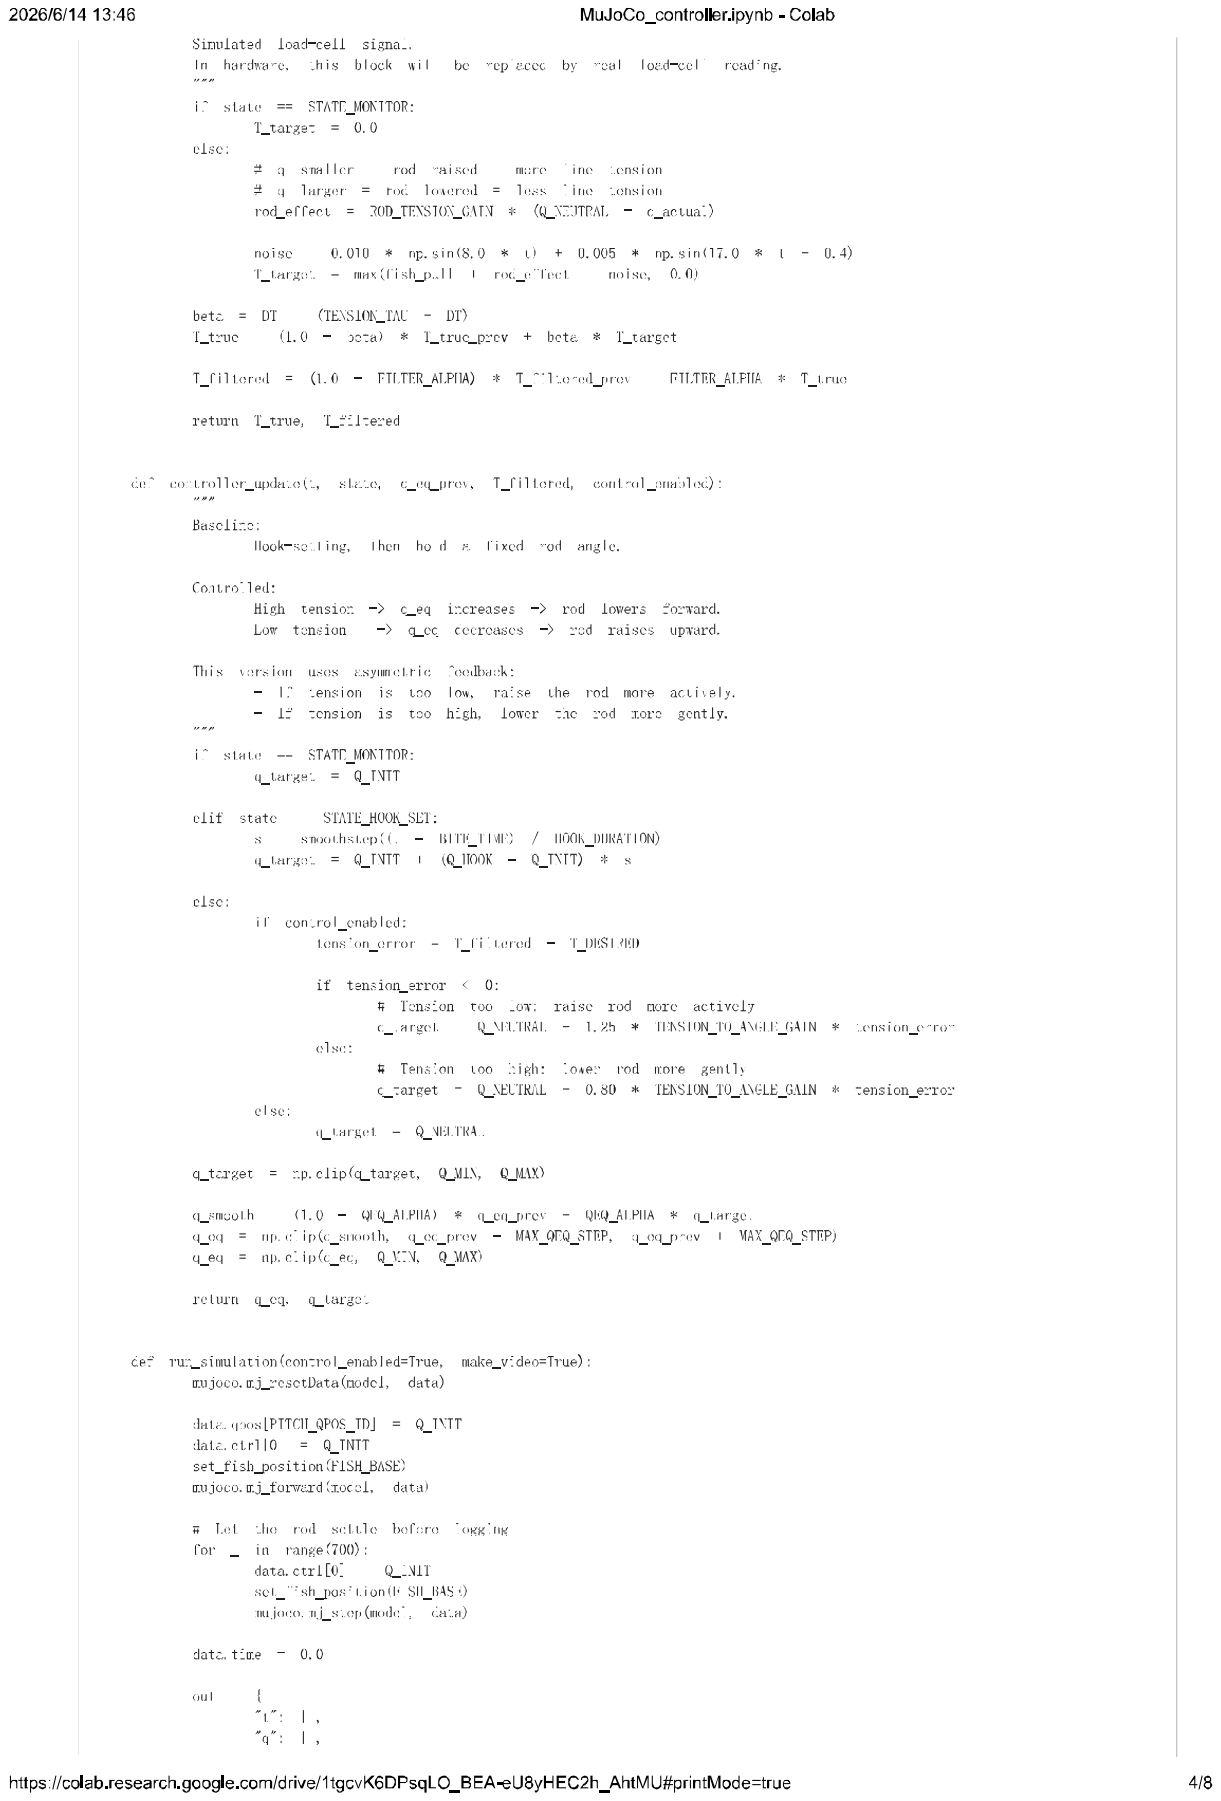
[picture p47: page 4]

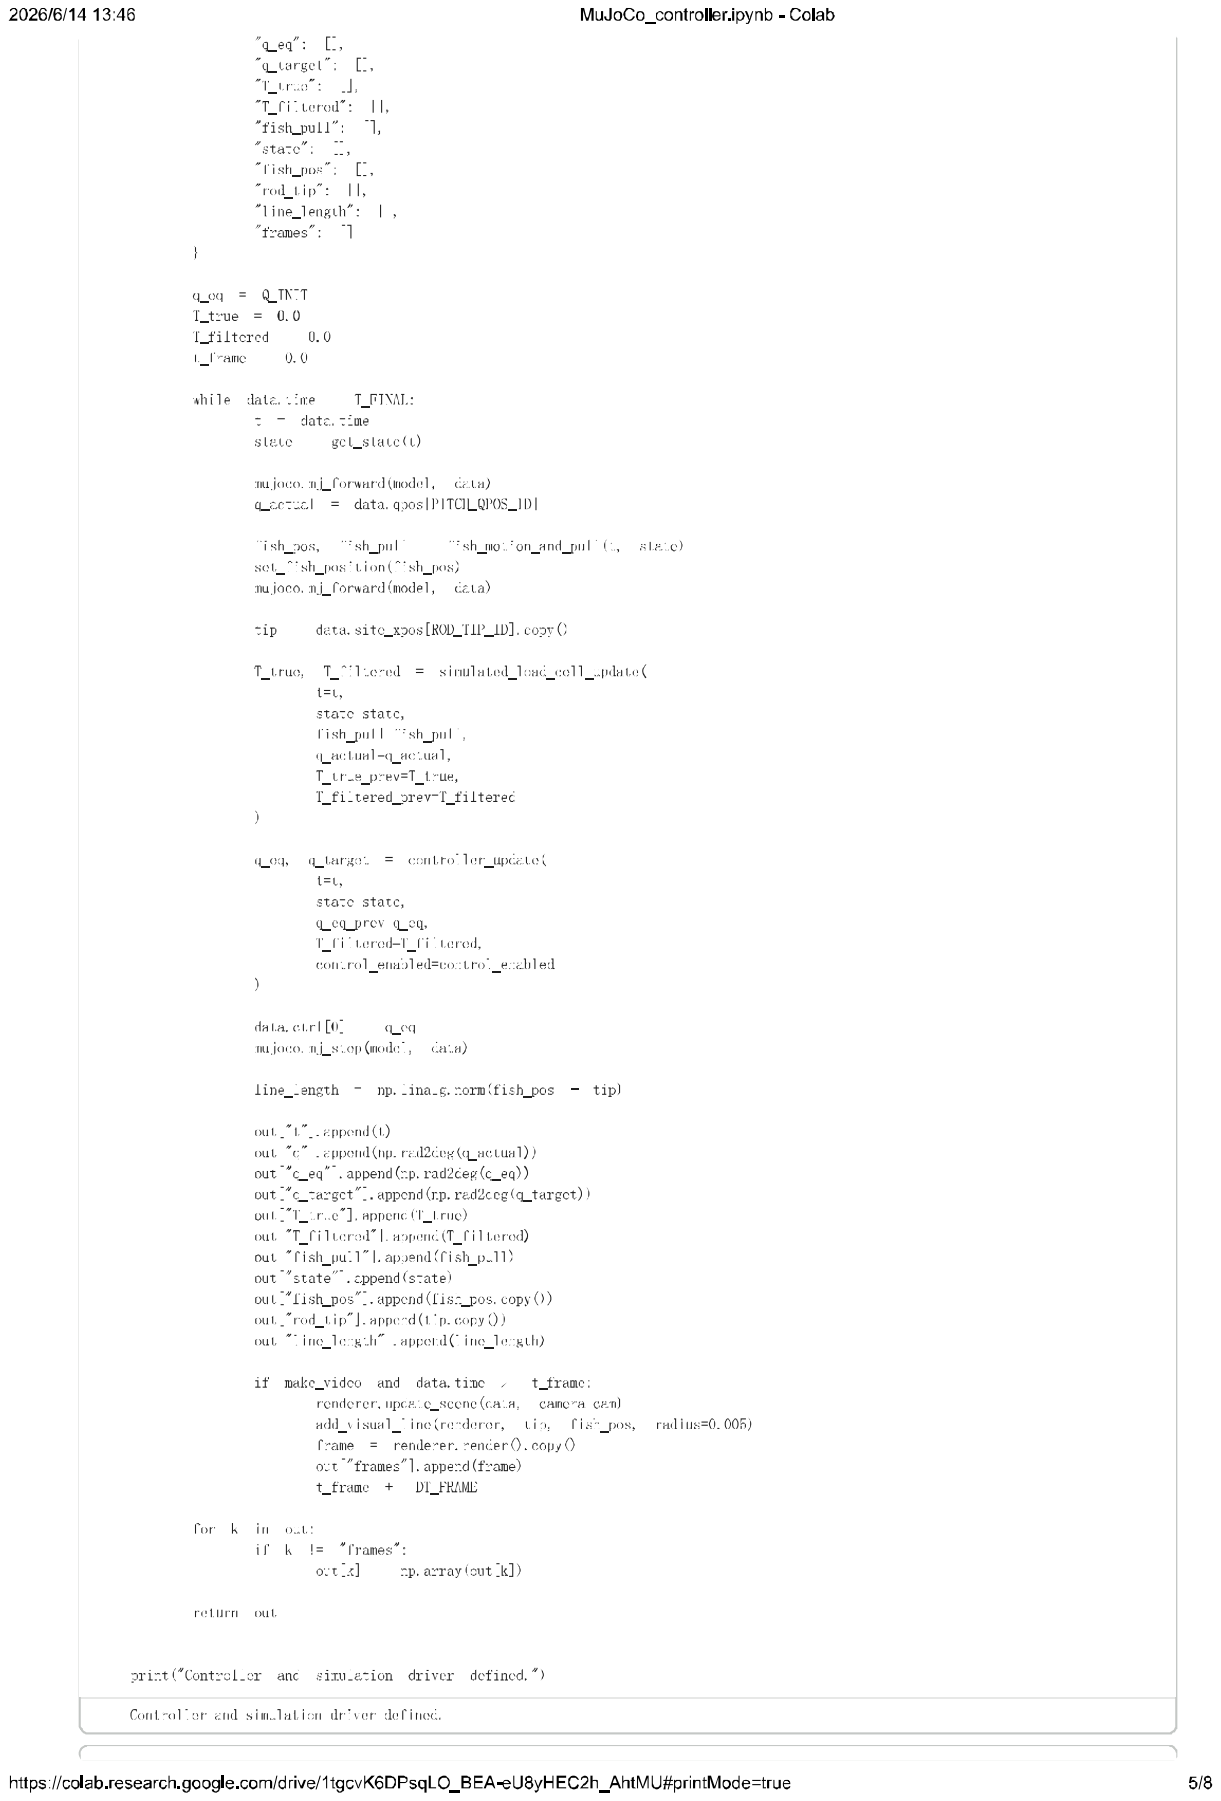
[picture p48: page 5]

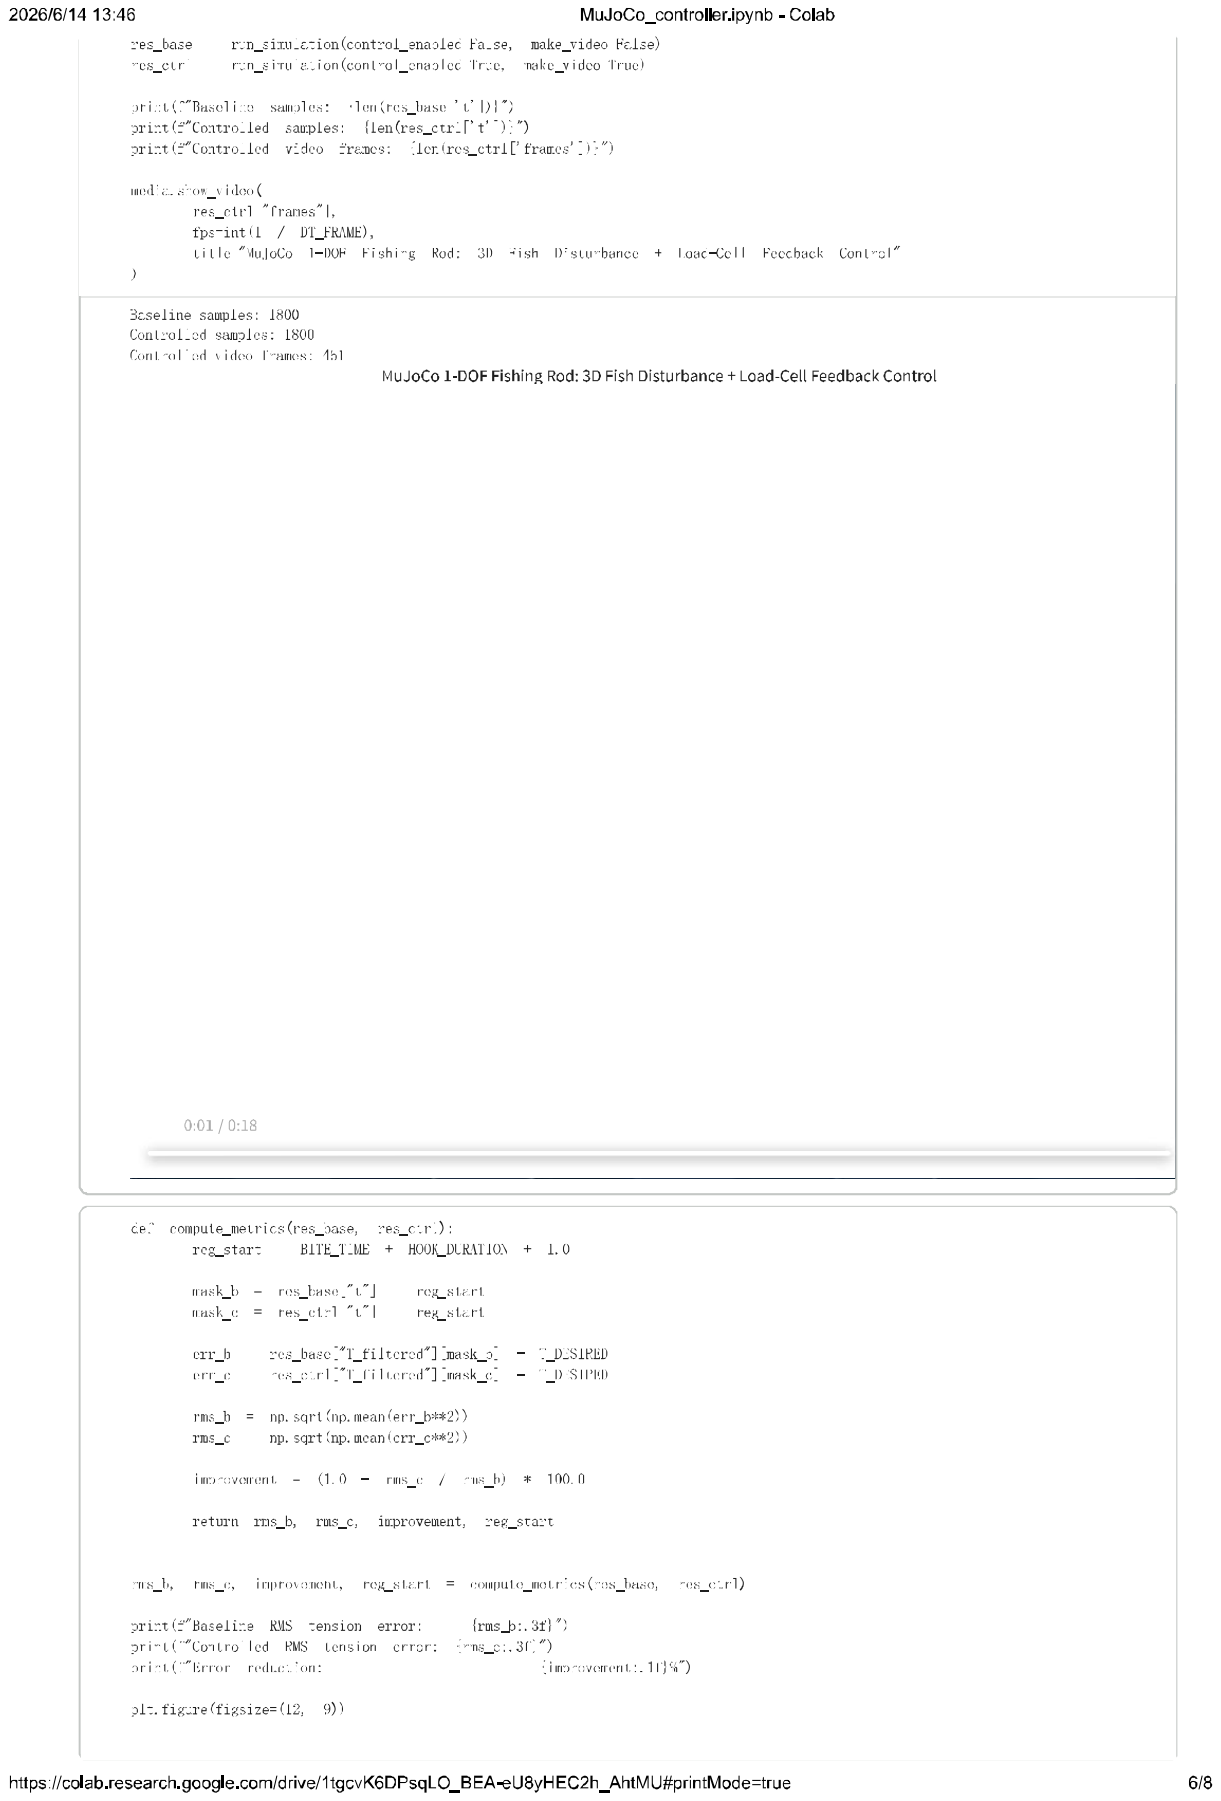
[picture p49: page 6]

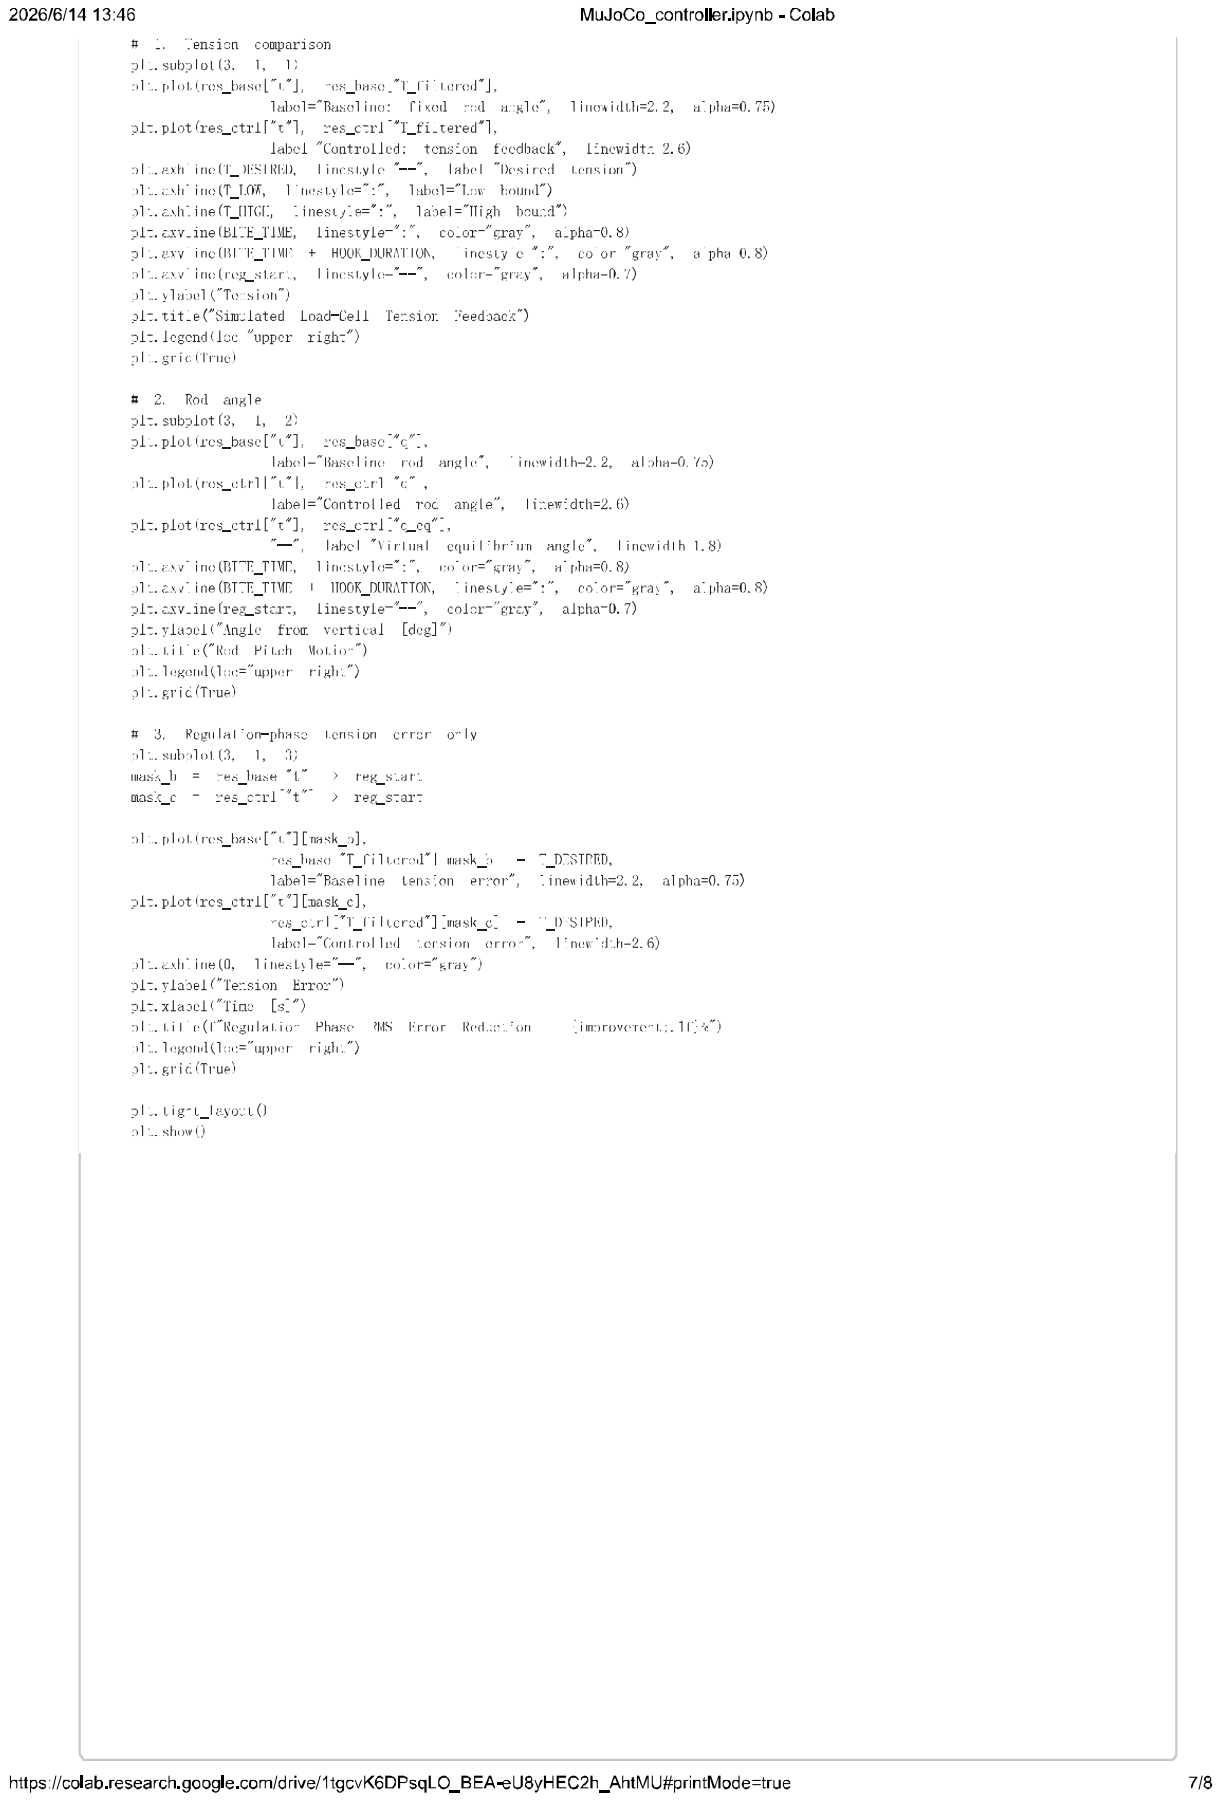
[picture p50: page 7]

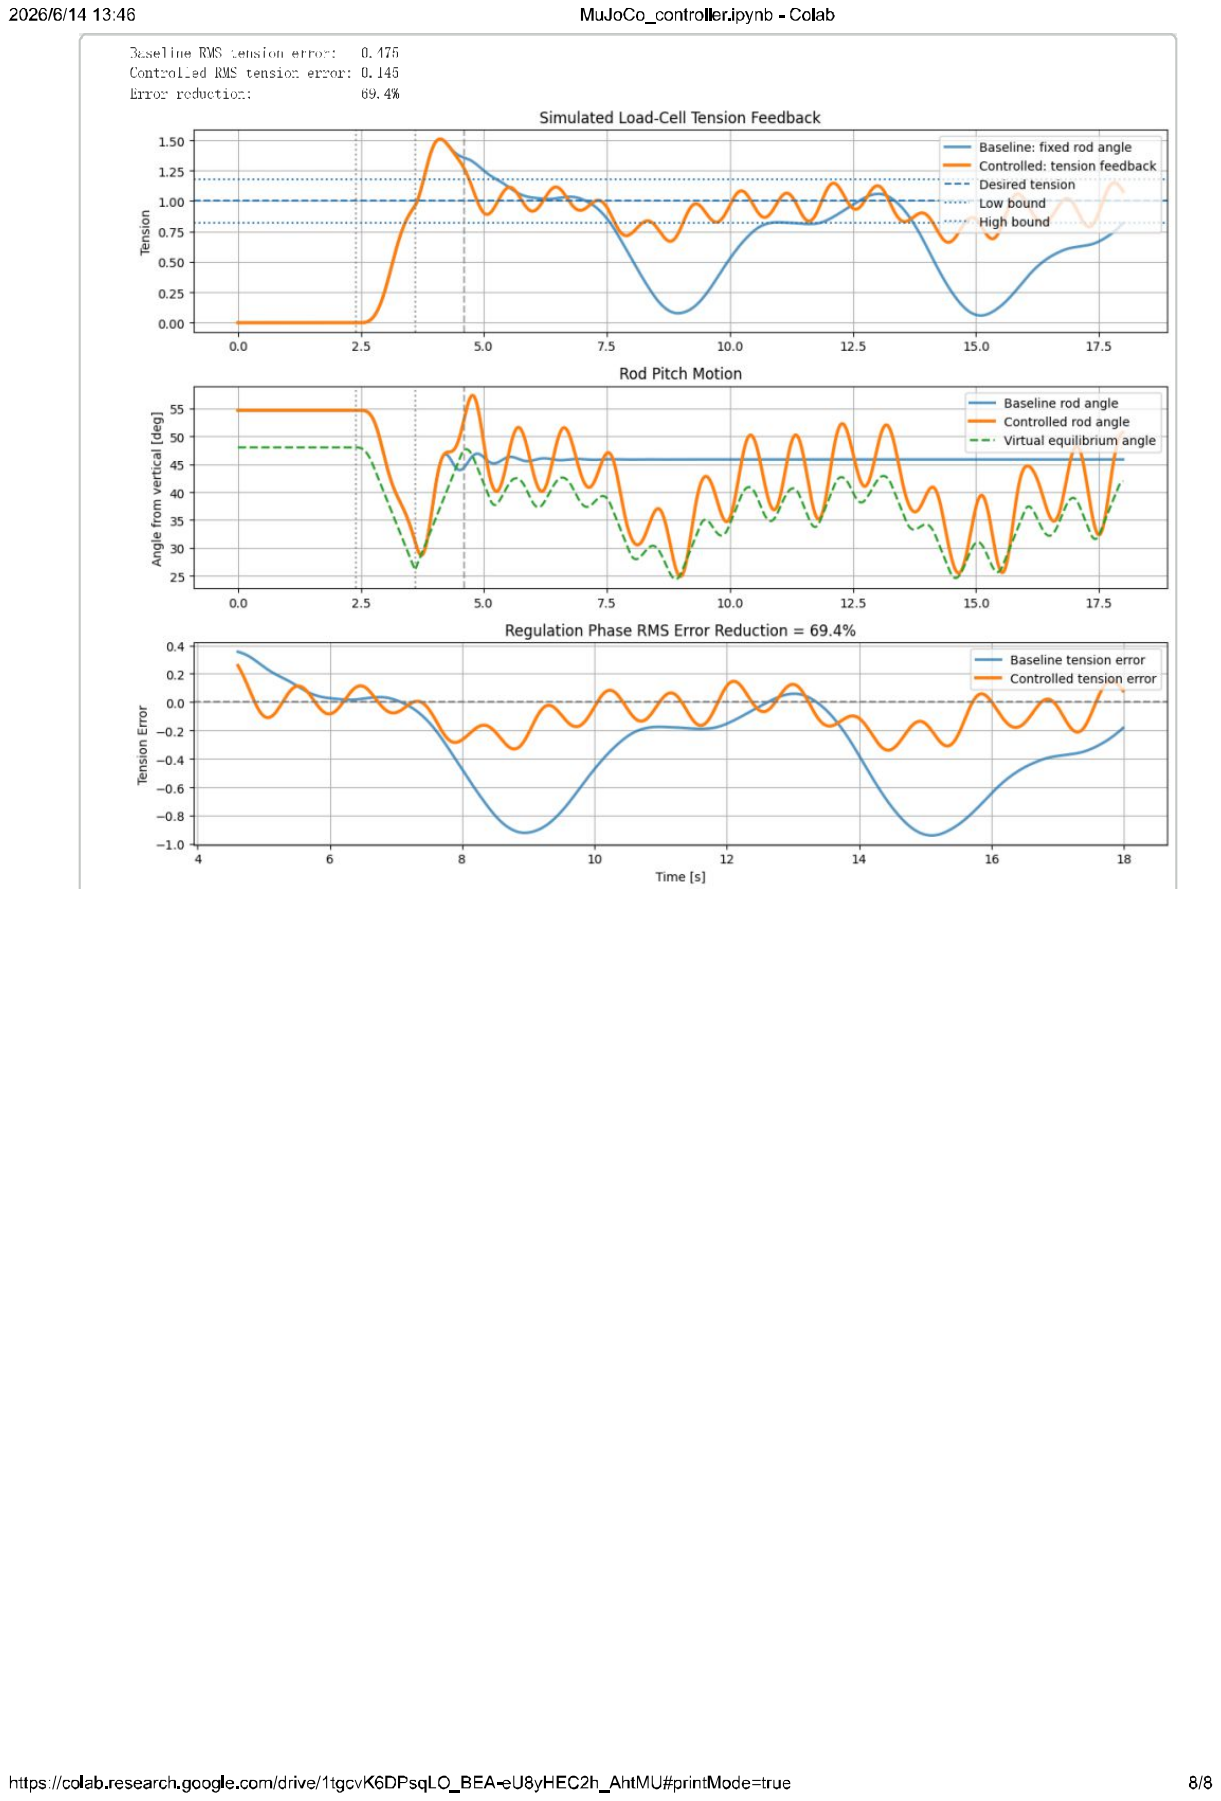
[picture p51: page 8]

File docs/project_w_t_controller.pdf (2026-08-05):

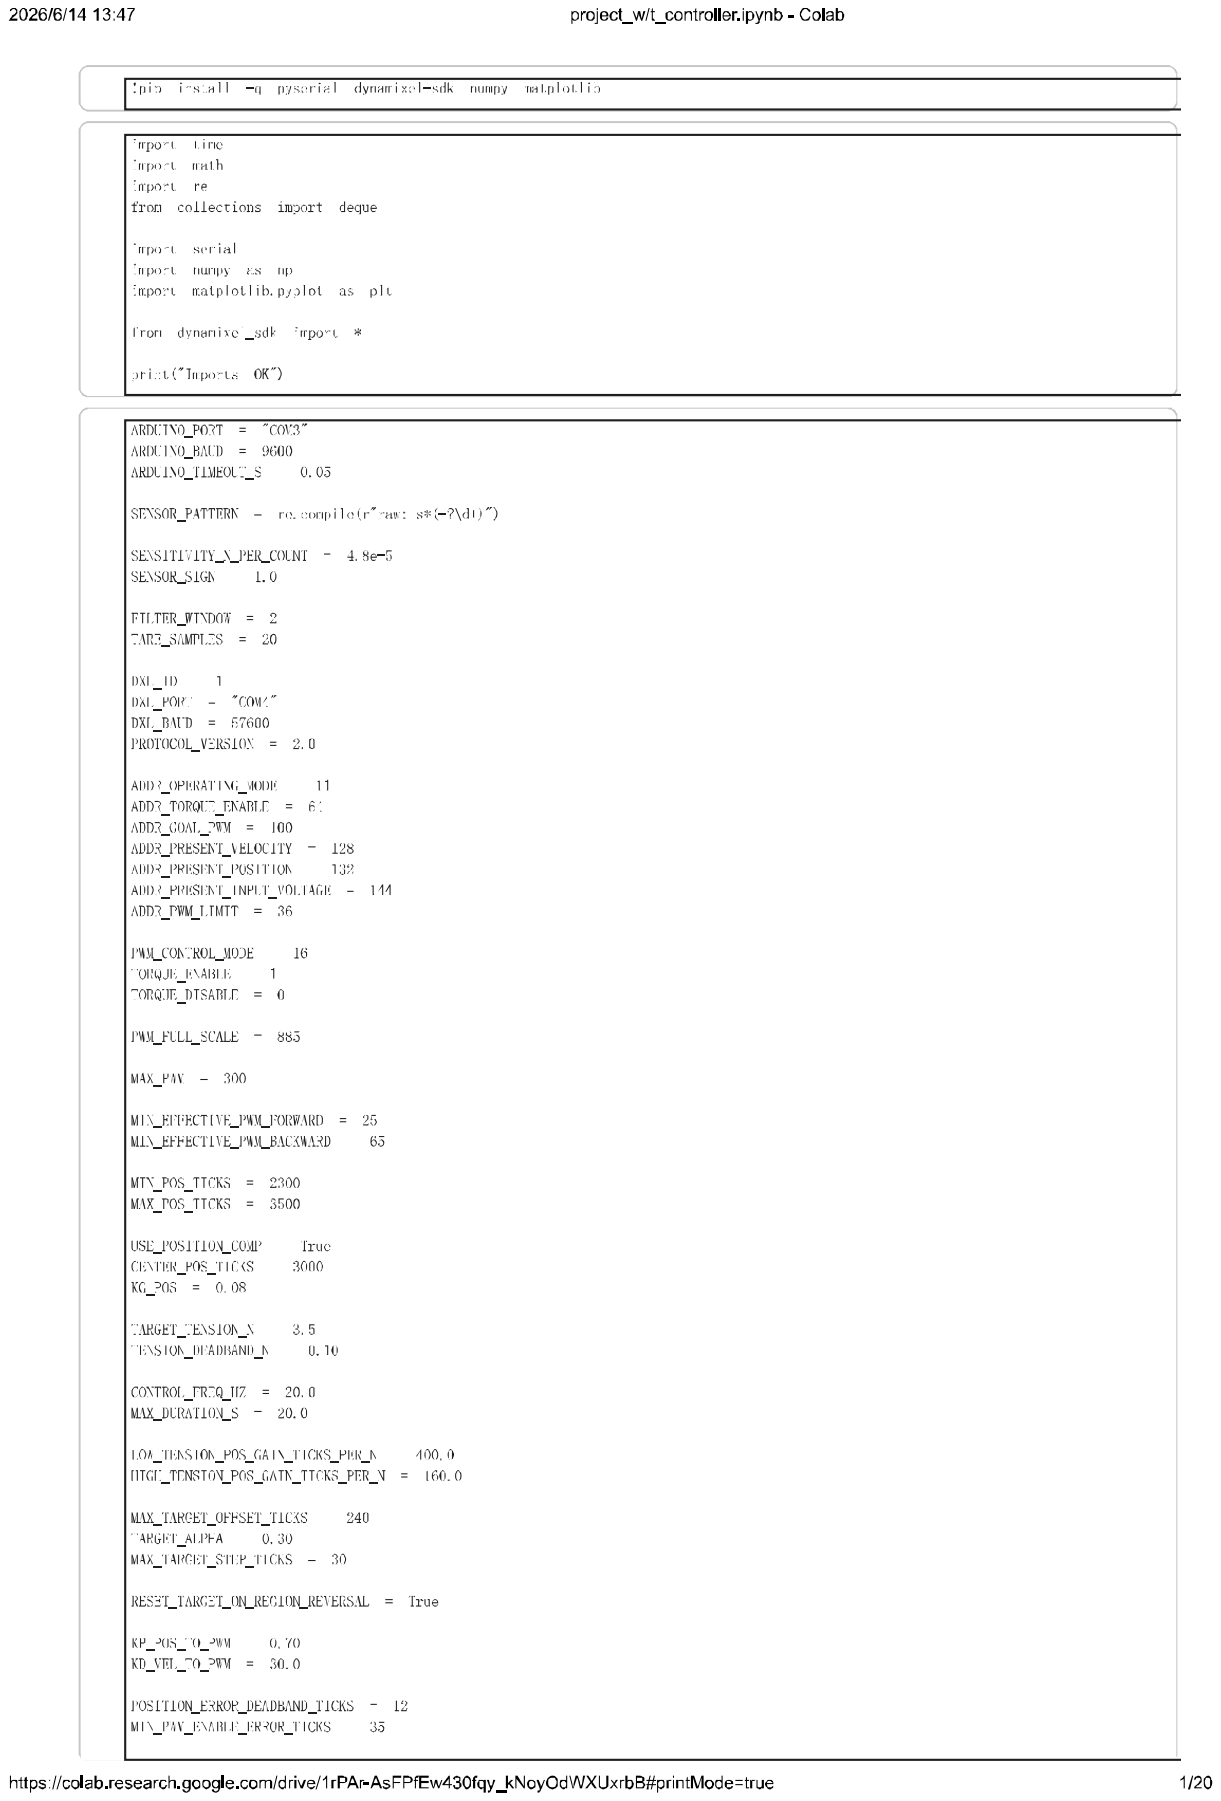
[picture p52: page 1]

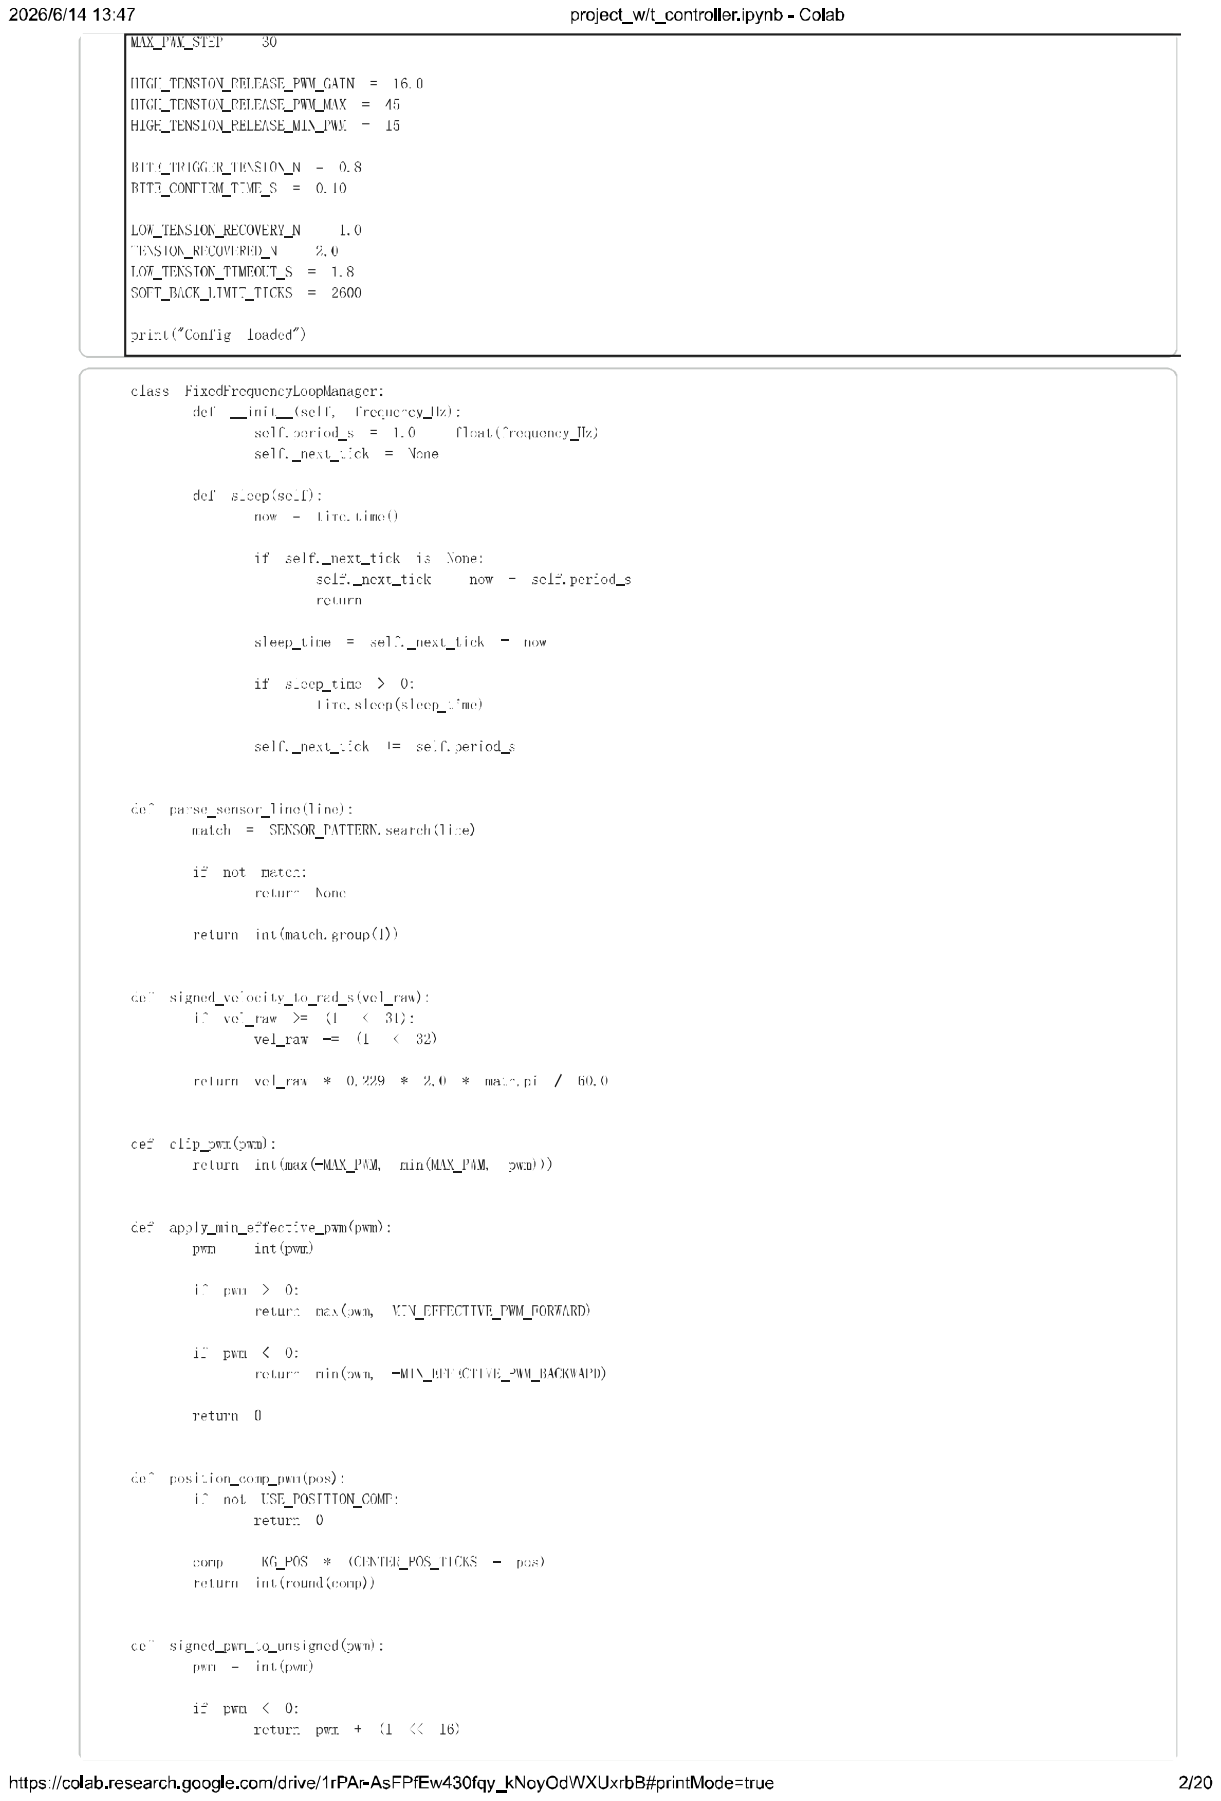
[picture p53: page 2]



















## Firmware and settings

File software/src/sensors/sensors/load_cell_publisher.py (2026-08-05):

#!/usr/bin/env python3
import math
from collections import deque
from typing import Optional

import rclpy
import serial
from rclpy.node import Node
from geometry_msgs.msg import WrenchStamped
from interfaces.msg import FishingTension
from tf2_ros import Buffer, TransformListener

from sensors.arduino_load_cell import ArduinoLoadCellReader


class LoadCellPublisher(Node):
    def __init__(self):
        # Node name matches the key in sensor_params.yaml so params load correctly.
        super().__init__('load_cell_node')

        # Defensive Coding: Parameterization (No Magic Numbers).
        self.declare_parameter('calibration_offset', 0.0)
        self.declare_parameter('calibration_scale', 1.0)
        self.declare_parameter('use_moving_average', True)
        self.declare_parameter('window_size', 10)
        self.declare_parameter('publish_frequency', 80.0)
        self.declare_parameter('tension_max_threshold', 20.0)
        self.declare_parameter('noise_floor', 0.1)
        self.declare_parameter('frame_id', 'rod_tip_link')
        # Target line tension (published for diagnostics overlays; the controllers
        # own the real setpoint, this just annotates the recorded signal).
        self.declare_parameter('target_tension', 3.5)
        # 'hardware' = HX711 via Arduino serial; 'sim_fts' = MuJoCo line-tension estimate.
        self.declare_parameter('source', 'hardware')
        self.declare_parameter('wrench_topic', '/tension_sensor_broadcaster/wrench')
        # Arduino HX711 path (project_w_t_controller.ipynb protocol).
        self.declare_parameter('arduino_port', '/dev/ttyACM0')
        self.declare_parameter('arduino_baud', 9600)
        self.declare_parameter('arduino_timeout_s', 0.05)
        self.declare_parameter('tare_on_start', True)
        self.declare_parameter('tare_samples', 20)
        self.declare_parameter('sensor_sign', 1.0)
        self.declare_parameter('sensor_line_filter_window', 2)
        # Sim stretch model (matches fishing-robot_sim.xml tendon parameters).
        self.declare_parameter('sim_line_stiffness', 220.0)
        self.declare_parameter('sim_line_springlength', 0.20)
        self.declare_parameter('sim_line_damping', 1.5)
        self.declare_parameter('sim_rod_frame', 'rod_tip_link')
        self.declare_parameter('sim_fish_frame', 'fish_link')

        self.calibration_offset = self.get_parameter('calibration_offset').value
        self.calibration_scale = self.get_parameter('calibration_scale').value
        self.use_moving_average = self.get_parameter('use_moving_average').value
        self.window_size = int(self.get_parameter('window_size').value)
        self.publish_frequency = self.get_parameter('publish_frequency').value
        self.tension_max_threshold = self.get_parameter('tension_max_threshold').value
        self.noise_floor = self.get_parameter('noise_floor').value
        self.frame_id = self.get_parameter('frame_id').value
        self.target_tension = float(self.get_parameter('target_tension').value)
        self.source = self.get_parameter('source').value
        self.wrench_topic = self.get_parameter('wrench_topic').value
        self.arduino_port = self.get_parameter('arduino_port').value
        self.arduino_baud = int(self.get_parameter('arduino_baud').value)
        self.arduino_timeout_s = float(self.get_parameter('arduino_timeout_s').value)
        self.tare_on_start = bool(self.get_parameter('tare_on_start').value)
        self.tare_samples = int(self.get_parameter('tare_samples').value)
        self.sensor_sign = float(self.get_parameter('sensor_sign').value)
        self.sensor_line_filter_window = int(
            self.get_parameter('sensor_line_filter_window').value)
        self.sim_line_stiffness = self.get_parameter('sim_line_stiffness').value
        self.sim_line_springlength = self.get_parameter('sim_line_springlength').value
        self.sim_line_damping = self.get_parameter('sim_line_damping').value
        self.sim_rod_frame = self.get_parameter('sim_rod_frame').value
        self.sim_fish_frame = self.get_parameter('sim_fish_frame').value

        self.publisher_ = self.create_publisher(FishingTension, '/fishing_arm/tension', 10)
        self.buffer = deque(maxlen=self.window_size)

        self._latest_force = None
        self._prev_line_length = None
        self._prev_line_time = None
        self._arduino: Optional[ArduinoLoadCellReader] = None
        self._last_filtered_raw: Optional[float] = None
        self._last_tension = 0.0
        self._hardware_samples = 0

        if self.source == 'sim_fts':
            self._tf_buffer = Buffer()
            self._tf_listener = TransformListener(self._tf_buffer, self)
            self.wrench_sub = self.create_subscription(
                WrenchStamped, self.wrench_topic, self._wrench_cb, 10)
        elif self.source == 'hardware':
            self._init_hardware_reader()

        self.timer_period = 1.0 / self.publish_frequency
        self.timer = self.create_timer(self.timer_period, self.timer_callback)
        self.time_counter = 0.0

        self.get_logger().info(
            f'Load Cell Publisher initialized at {self.publish_frequency:.1f} Hz '
            f'(source: {self.source}, frame: {self.frame_id}).')

    def _init_hardware_reader(self) -> None:
        reader = ArduinoLoadCellReader(
            port=self.arduino_port,
            baud=self.arduino_baud,
            timeout_s=self.arduino_timeout_s,
            filter_window=self.sensor_line_filter_window,
            tare_samples=self.tare_samples,
        )
        try:
            reader.open()
        except serial.SerialException as exc:
            raise RuntimeError(
                f'Failed to open Arduino load cell on {self.arduino_port}: {exc}',
            ) from exc

        zero_offset = self.calibration_offset
        if self.tare_on_start:
            self.get_logger().info(
                'Taring load cell — keep the line unloaded for a moment...')
            zero_offset = reader.tare()
            self.get_logger().info(f'Tare complete. zero_offset={zero_offset:.1f}')
        else:
            reader.zero_offset = zero_offset
            self.get_logger().info(
                f'Using fixed calibration_offset={zero_offset:.1f} (tare_on_start=false)',
            )

        self._arduino = reader
        self.calibration_offset = zero_offset
        self.get_logger().info(
            f'Arduino HX711 reader active on {self.arduino_port} @ {self.arduino_baud} baud, '
            f'scale={self.calibration_scale:.6g} N/count.',
        )

    def destroy_node(self) -> bool:
        if self._arduino is not None:
            self._arduino.close()
            self._arduino = None
        return super().destroy_node()

    def _wrench_cb(self, msg):
        f = msg.wrench.force
        self._latest_force = (f.x, f.y, f.z)

    def _line_length_from_tf(self) -> Optional[float]:
        try:
            tf = self._tf_buffer.lookup_transform(
                self.sim_rod_frame,
                self.sim_fish_frame,
                rclpy.time.Time(),
            )
        except Exception:
            return None
        t = tf.transform.translation
        return math.sqrt(t.x * t.x + t.y * t.y + t.z * t.z)

    def _sim_stretch_tension(self) -> Optional[float]:
        """Hooke's-law line model: k*(L-L0) + c*dL/dt (matches MJCF tendon)."""
        length = self._line_length_from_tf()
        if length is None:
            return None

        stretch = max(length - self.sim_line_springlength, 0.0)
        tension = self.sim_line_stiffness * stretch

        now = self.get_clock().now()
        if self._prev_line_length is not None and self._prev_line_time is not None:
            dt = (now - self._prev_line_time).nanoseconds / 1e9
            if dt > 1e-6:
                rate = (length - self._prev_line_length) / dt
                if rate > 0.0:
                    tension += self.sim_line_damping * rate

        self._prev_line_length = length
        self._prev_line_time = now
        return max(tension, 0.0)

    def _raw_to_newtons(self, filtered_raw: float) -> float:
        return (
            self.sensor_sign
            * self.calibration_scale
            * (filtered_raw - self.calibration_offset)
        )

    def read_hardware_tension_newtons(self) -> Optional[float]:
        """Read one Arduino sample; return None if no new line this cycle."""
        if self._arduino is None:
            return None
        filtered_raw = self._arduino.read_filtered_raw()
        if filtered_raw is None:
            return None
        self._last_filtered_raw = filtered_raw
        self._hardware_samples += 1
        return self._raw_to_newtons(filtered_raw)

    def read_tension_newtons(self) -> float:
        if self.source == 'sim_fts':
            stretch_tension = self._sim_stretch_tension()
            if stretch_tension is not None:
                return stretch_tension
            if self._latest_force is None:
                return 0.0
            fx, fy, fz = self._latest_force
            return math.sqrt(fx * fx + fy * fy + fz * fz)

        tension = self.read_hardware_tension_newtons()
        if tension is not None:
            self._last_tension = tension
            return tension
        # Hold last reading until the next serial line arrives.
        return self._last_tension

    def timer_callback(self):
        tension = self.read_tension_newtons()

        if abs(tension) < self.noise_floor:
            tension = 0.0

        if self.use_moving_average:
            self.buffer.append(tension)
            tension = sum(self.buffer) / len(self.buffer)

        msg = FishingTension()
        msg.header.stamp = self.get_clock().now().to_msg()
        msg.header.frame_id = self.frame_id
        msg.tension_newtons = float(tension)
        msg.target_tension_newtons = self.target_tension
        self.publisher_.publish(msg)

        if tension > self.tension_max_threshold:
            self.get_logger().warn(
                f'Line tension {tension:.2f} N exceeds threshold '
                f'{self.tension_max_threshold:.2f} N.')

        if int(self.time_counter * self.publish_frequency) % int(self.publish_frequency) == 0:
            detail = ''
            if self.source == 'hardware' and self._last_filtered_raw is not None:
                detail = f' (raw={self._last_filtered_raw:.0f})'
            self.get_logger().info(f'Publishing line tension: {tension:.2f} N{detail}')

        self.time_counter += self.timer_period


def main(args=None):
    rclpy.init(args=args)
    node = LoadCellPublisher()
    try:
        rclpy.spin(node)
    except KeyboardInterrupt:
        pass
    finally:
        node.destroy_node()
        rclpy.shutdown()


if __name__ == '__main__':
    main()

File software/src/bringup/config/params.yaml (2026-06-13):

# Shared fishing tension controllers (Julie admittance + Chaoyi force feedback).
# Select at launch: controller_type:=admittance | force_feedback | none

admittance_controller:
  ros__parameters:
    target_tension: 3.5
    safety_tension_limit: 20.0

    # 1DOF mode (notebook-equivalent): control pitch_joint only; lock base_joint.
    control_dof: 1
    pitch_joint: Joint_2
    base_joint: Joint_1
    joint_1_hold: 1.57   # base_joint lock angle (rad)

    # Pitch setpoints (rad). Smaller = rod raised = higher tension.
    q_init: 1.745
    q_hook: 1.40
    q_neutral: 1.605
    q_min: 0.10
    q_max: 2.20

    bite_time: 2.4
    hook_duration: 1.2
    fsm_enabled: true
    tension_filter_alpha: 0.055
    control_rate_hz: 50.0

    # Julie admittance (virtual mass-spring-damper)
    m_v: 0.6
    b_v: 5.5
    k_v: 20.0
    k_f: 8.0
    kp_track: 140.0
    kd_track: 20.0
    ki_track: 0.0
    k_g: 9.95
    rod_length: 0.185
    j_alpha: 0.05
    pos_int_limit: 0.15
    max_torque: 20.0

force_feedback_controller:
  ros__parameters:
    target_tension: 3.5
    safety_tension_limit: 20.0

    control_dof: 1
    pitch_joint: Joint_2
    base_joint: Joint_1
    joint_1_hold: 1.57

    q_init: 1.745
    q_hook: 1.40
    q_neutral: 1.605
    q_min: 0.10
    q_max: 2.20

    bite_time: 2.4
    hook_duration: 1.2
    fsm_enabled: true
    tension_filter_alpha: 0.055
    control_rate_hz: 50.0

    # Chaoyi asymmetric proportional feedback (tuned for 3.5 N target in MuJoCo)
    tension_to_angle_gain: 0.261799   # rad/N (~15 deg/N)
    qeq_alpha: 0.04
    max_qeq_step: 0.00384             # rad (~0.22 deg)
    raise_gain: 1.25
    lower_gain: 0.80

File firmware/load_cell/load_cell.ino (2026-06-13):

/*
 * HX711 load cell → USB serial for the ROS load_cell_node.
 *
 * Protocol (matches software/src/sensors/sensors/arduino_load_cell.py):
 *   raw: <integer>\n
 *
 * Wiring (Arduino Mega 2560): DT → pin 3, SCK → pin 2
 * Flash: firmware/scripts/flash.sh
 */
#include "HX711.h"

#define HX711_DT 3
#define HX711_SCK 2

// ~40 Hz matches ROS publish_rate; HX711 needs time per conversion.
static const unsigned long SAMPLE_PERIOD_MS = 25;
static const uint8_t AVERAGE_SAMPLES = 5;

HX711 scale;

void setup() {
  Serial.begin(9600);
  scale.begin(HX711_DT, HX711_SCK);
  scale.set_scale(1.0f);
  scale.tare(AVERAGE_SAMPLES);

  // Banner is ignored by the ROS parser (non-matching lines).
  Serial.println(F("load_cell firmware ready"));
  delay(500);
}

void loop() {
  static unsigned long last_ms = 0;
  unsigned long now = millis();
  if (now - last_ms < SAMPLE_PERIOD_MS) {
    return;
  }
  last_ms = now;

  if (!scale.is_ready()) {
    Serial.println(F("HX711 not ready"));
    return;
  }

  long raw = scale.read_average(AVERAGE_SAMPLES);
  Serial.print(F("raw: "));
  Serial.println(raw);
}

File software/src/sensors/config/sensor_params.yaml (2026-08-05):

# Configuration for the Fishing Arm Load Cell (HX711 via Arduino serial).
load_cell_node:
  ros__parameters:
    # --- Arduino serial (matches project_w_t_controller.ipynb) ---
    arduino_port: "/dev/ttyACM0"
    arduino_baud: 9600
    arduino_timeout_s: 0.05
    tare_on_start: true
    tare_samples: 20
    sensor_sign: 1.0
    sensor_line_filter_window: 2

    # --- Physical calibration ---
    # Used when tare_on_start=false; overwritten by live tare otherwise.
    calibration_offset: 0.0
    # N per raw ADC count. Notebook used 4.8e-5; tune on your rig.
    calibration_scale: 0.000048

    # --- Signal processing ---
    use_moving_average: true
    window_size: 10
    publish_frequency: 80.0

    # --- Safety / operational limits ---
    tension_max_threshold: 20.0
    noise_floor: 0.1

    frame_id: "rod_tip_link"
    target_tension: 3.5

    # --- Simulation stretch model (must match fishing-robot_sim.xml tendon) ---
    sim_line_stiffness: 220.0
    sim_line_springlength: 0.20
    sim_line_damping: 1.5
    sim_rod_frame: "rod_tip_link"
    sim_fish_frame: "fish_link"

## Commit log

2026-05-07 Add CAD assets and placeholder files
    Add MX-28AT CAD assets and related assembly plus placeholder text files. Files added: CAD/assets/MX-28AT_AR.SLDPRT (SolidWorks part, binary), CAD/assets/MX-28AT_AR.stp (STEP export, large), CAD/fishi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
    [MX-28AT_AR.SLDPRT, MX-28AT_AR.stp, fishing_assy.SLDASM]
2026-05-09 Add CAD parts and assemblies; update fishing assy
    Add SolidWorks parts and assemblies for the project (rod.SLDPRT, rod-v2.SLDPRT, rod_assy.SLDASM, load-cell.SLDPRT) and update fishing_assy.SLDASM. Several SolidWorks temporary/autosave files (~$*) we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
    [fishing_assy.SLDASM, load-cell.SLDPRT, rod-v2.SLDPRT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]
2026-05-13 Update CAD assemblies, add rod-v3 & fishing_assy2
    Clean up temporary SolidWorks autosave files and update assemblies: remove CAD/assets/~$MX-28AT_AR.SLDPRT, CAD/assets/~$load-cell.SLDPRT, CAD/~$fishing_assy.SLDASM, CAD/~$rod-v2.SLDPRT, and CAD/~$rod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
    [fishing_assy.SLDASM, fishing_assy2.SLDASM, rod-v3.SLDPRT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]
2026-05-27 urdf reorg
    [Link_1_collision.STL, Link_2_collision.STL, base_link_collision.STL]
2026-05-27 mujoco config
    [Link_1.STL, Link_1_collision.STL, Link_2.STL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]
2026-05-27 adding to codebase
    [fishing-robot_sim.xml]
2026-05-28 Update SolidWorks CAD parts and assemblies
    Refresh multiple SolidWorks models: MX-28AT_AR.SLDPRT, rod-v2.SLDPRT, rod_assy.SLDASM, and assy2/fishing_assy2.SLDASM. These are binary model updates reflecting design revisions (geometry/fit/assembl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
    [MX-28AT_AR.SLDPRT, fishing_assy2.SLDASM, rod-v2.SLDPRT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]
2026-05-28 Add fishing_assy2 STL files
    Add four binary STL exports under CAD/assy2/STL for the fishing_assy2 assembly: Part1, Part2, rod_assy-1 Part1, and rod_assy-1 rod-v2-1. These files provide the 3D geometry for the assembly and rod c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
    [fishing_assy2 - Part1^fishing_assy2-1.STL, fishing_assy2 - Part2^fishing_assy2-1.STL, fishing_assy2 - rod_assy-1 Part1^rod_assy-1.STL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]
2026-05-30 sim setup and data recording
    [controllers.yaml, fishing-robot.urdf.xacro, fishing-robot_sim.xml]
2026-06-08 Add schematics, update CAD assembly, move notebook
    Update CAD assembly file and add Fritzing schematics for the project. Added docs/schematic/HX711 Weighing Sensor Module.fzpz, docs/schematic/Rectangle Load Cell.fzpz, and docs/schematic/fishing-bot.f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
    [fishing-bot.fzz, fishing_assy2.SLDASM]
2026-06-12 Add final presentation PDFs
    Add two PDF files to docs: 'final presentation.pdf' (current) and 'final presentation (old).pdf' (previous version) to keep both the final presentation and its prior copy for reference.
2026-06-13 control tests
    [controllers_hw.yaml, fishing-robot.urdf.xacro, fishing-robot_sim.xml]
2026-06-14 Organize docs: move presentations & add report
    Relocate presentation files into docs/presentation/ (including many PPTX internals and media), add final presentation PPTX, move final report-related files into docs/report/, and add FinalReport.pdf.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
    [fishing_assy2.SLDASM]
